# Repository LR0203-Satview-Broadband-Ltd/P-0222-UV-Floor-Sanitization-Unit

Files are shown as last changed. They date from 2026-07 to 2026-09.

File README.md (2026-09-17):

# P-0222 | UV Floor Sanitization Unit

> Low-voltage custom PCB replacing an Arduino-based prototype for a hospital UV floor sanitization platform.

| Project | Status | Current package | Owner |
| --- | --- | --- | --- |
| P-0222 | Released | First Release v1 package complete and ready for supplier release | Ing. Vega Maximiliano |

## Project Overview

Satview Broadband Ltd. is developing a UV foot-sanitizing floor unit for hospital environments. This project replaces the prototype controller with a professional PCB that manages the UV cycle, relay actuation, protected 24 VDC input, power regulation, timer selection, and external component connections.

The current released baseline for the project is the PRD v1.1 package in `project_docs/requirements/PRD v1.1.md`. The design remains under Logic Reliance engineering processes and follows the project requirements, acceptance criteria, and KiCad library governance defined for the work.

## Current Status

The PCB, schematic, and manufacturing reviews were completed. First Release v1 was completed on 2026-08-28 and is ready for supplier release. Review updates include the C5, C7, and C12 part numbers and the D1 and R7 values and part numbers. Review records remain available in `project_docs/requirements/Reviews.md`.

### Package Contents

- BOM: 40 grouped entries and 70 component references.
- Assembly positions: pick-and-place files generated; DNP handling is recorded in the BOM and review notes.
- Component sourcing: manufacturer, MPN, and DigiKey fields populated in the current EBOM.
- Fabrication outputs: Gerbers, ODB++, PTH/NPTH drills, assembly files, drawings, and 3D model present.
- Surface finish: `ENEPIG`.
- Board UID and board specifications added to the `F.Fab` layer and assembly drawing.
- Manufacturing drill outputs: duplicate PTH/NPTH files removed.
- Logic Reliance BOM workbook: editable Excel version generated from the KiCad CSV.

## Technical Scope

- Requirements traceability and acceptance criteria.
- Electrical sizing and power regulation validation.
- STM32C011F6 MCU control.
- Relay-driven UV load switching.
- Reverse-polarity, surge, fuse, and transient protection.
- Configurable cycle timer through DIP switches.
- KiCad schematic capture, PCB layout, manufacturing outputs, and supporting evidence.

## Design Boundaries

This iteration includes the low-voltage PCB only.

Out of scope:

- 120 VAC design, which remains within the external certified power supply.
- Mechanical enclosure design.
- Regulatory certification.
- UV strip sourcing and final optical characterization.

## Manufacturing Package

The manufacturing package is delivered as:

`pcb_0222/outputs/Manufacture/20260828-P_0222_manufacture.zip`

| Directory or file | Purpose |
| --- | --- |
| `Manufacture.Files.rev20280828.zip` | Manufacturing files package |
| `Design.Files.rev20280828.zip` | Design source files |
| `EBOM.rev202608288.xlsx` | Logic Reliance electronic BOM |
| `Mechanical.outputs.rev20280828.zip` | Mechanical outputs |
| `schematics.rev20280828.pdf` | Schematic PDF |
| `Top.View.rev2080828.png` | Board top-view image |

The complete First Release v1 package is available at `pcb_0222/outputs/Releases/v1_20260828/`.

## Repository Contents

This is the controlled inventory of publishable project content. Local process notes, AI working files, and internal assistant configuration are intentionally excluded from publication.

| Directory | Contents |
| --- | --- |
| `pcb_0222/` | KiCad project, schematic, PCB, local library assets, and manufacturing outputs |
| `project_docs/design/` | MCU boot, pinout, power supply, and implementation records |
| `project_docs/datasheets/` | Manufacturer datasheets and component package evidence |
| `project_docs/references/` | External technical references used for engineering decisions |
| `project_docs/requirements/` | Released PRD and processor requirements |

### Design Records

- `mcu_boot/`
- `mcu_pinout/`
- `power_supply/`

### Datasheet Categories

`buttons/` · `conectors/` · `debugger/` · `dipswitch/` · `inductor/` · `leds/` · `mcu/` · `nails/` · `npn/` · `pmos/` · `pptc/` · `psu/` · `relay/` · `rotary/` · `tvs/` · `xtal/` · `zenner/`

Some directory names preserve legacy spelling for traceability, including `conectors/` and `zenner/`.

## Key Documents

- [Project context baseline](p-0222.md)
- [Released PRD](project_docs/requirements/PRD%20v1.1.md)
- [Processor requirements](project_docs/requirements/Processor%20Requirements.md)
- [MCU boot and programming records](project_docs/design/mcu_boot/)
- [MCU pinout records](project_docs/design/mcu_pinout/)
- [Power supply records](project_docs/design/power_supply/)

## General Project Updates

- 2026-07-27: KiCad project files were uploaded and the schematic baseline was published.
- 2026-07-28: SWD programming guidance and STM32C0 BOOT0 handling were documented.
- 2026-07-29: Footprint and datasheet review entered the active validation cycle.
- 2026-07-30: Placement outputs, drawings, STEP model, and exchange artifacts were refreshed.
- 2026-08-02: Schematic review comments were incorporated into the PCB and manufacturing outputs.
- 2026-08-09: Layout placement and routing review continued with synchronized schematic and PCB updates.
- 2026-08-11: The active layout iteration was prepared for formal review.
- 2026-08-16: A preliminary manufacturing package was generated to support the pending layout review.
- 2026-08-16: Board UID and board specifications were added to the `F.Fab` layer and assembly drawing to improve manufacturing traceability.
- 2026-08-18: Repository documentation was refreshed to align the README, project baseline, and automation instructions with the current PRD v1.1 status and the pending formal layout review.
- 2026-08-27: Layout review passed; C5, C7, and C12 part numbers and D1 and R7 values and part numbers were updated.
- 2026-08-28: PCB, schematic, and manufacturing reviews were completed; First Release v1 artifacts were generated under `pcb_0222/outputs/Releases/v1_20260828/`.
- 2026-09-17: The `SP1103C-01UTG` schematic symbol was updated, with the related schematic and PCB project files synchronized.

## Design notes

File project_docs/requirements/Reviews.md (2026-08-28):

# Reviews

# Manufacturing Files Review 2026/08/27 (Blaž)

| | |
| --- | --- |
| 1 | The 3D generated contains the DNP parts as mounted. I don’t think it’s critical for this project, but it worths account for it in future projects.   |
| 2 | The BOM title block got a bit distorded:    Expected (example):   |
| 3 | The description column of the BOM file didn’t fill with the _Description_ field of the symbols but with the _Value_ field.   |
| 4 | I suggest not including schematics in the manufacturing files. This is make reverse engineering more difficult.   |
| 5 | I don’t think it worths adding the bottom silkscreen to the gerber files package as it doesn’t add any relevant information an it implies an additional manufacturing process.   |

# PCB Review 2026/08/26 (Blaž)

| | |
| --- | --- |
| 1 | Make sure there are not rule check errors:  |
| 2 | C3 and C15 are out of stock. But probably not a problem if the board is assembled on China.   |
| 3 | C5 similar case   |
| 4 | C7, C12 similar case   |
| 5 | D1 a bit more critical   |
| 6 | The silkscreen is missing the PCB version (it would be v1 in this case). Example below.   |
| 7 | Did the customer approve the inclusion of our logo in the PCB?   |

# PCB Review 2026/08/16 (Ruslan)

<div class="joplin-table-wrapper"><table style="width: 803px;"><tbody><tr><th colspan="1" rowspan="1" colwidth="49"><p data-id="takswppqcspu">1</p></th><td colspan="1" rowspan="1" colwidth="754"><p data-id="ryoquctkmlhi">Please add the board specs and board stack-up to the “Assembly” layer of the PCB design.</p><p data-id="rygyvwalnciz">Feel free to check an example from this design <a target="_blank" rel="noopener noreferrer nofollow" href="https://github.com/orgs/LR0201-Aura-Axis-Group-Inc/repositories">LR0201-Aura-Axis-Group-Inc repositories</a></p><p data-id="ayjezcmzgbbh">Here is an example:</p></td></tr><tr><th colspan="1" rowspan="1" colwidth="49"><p data-id="udgtshalslsv">2</p></th><td colspan="1" rowspan="1" colwidth="754"><p data-id="yvwvcpwyrcft">Lets add UID to the PCB. The spreadsheet is here: <a target="_blank" rel="noopener noreferrer nofollow" href="https://docs.google.com/spreadsheets/d/1bgarIeeIMzeJS9GwWEmvJlo1JK8DhYBbbADzcFZ2ea8/edit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">PCB UID - Google Sheets</a></p><p data-id="qlhqkcgbeopu">Here an example from a different project:</p><pre><code>PCB NAME
UID vX
[      ] (Blank Square)  </code></pre><p data-id="qwudojhfaxnv">For this project, it could be:</p><pre><code>UV Unit 
HW_00_UV_Unit v1
[      ]   </code></pre></td></tr></tbody></table></div>

# Schematic Review 2026/07/30

<div class="joplin-table-wrapper"><table style="width: 803px;"><tbody><tr><th colspan="1" rowspan="1" colwidth="49"><p data-id="wduerxznfdoq">1</p></th><td colspan="1" rowspan="1" colwidth="754"><p data-id="qwzypgariwlr">According to the PRD, there are X2 strip LED outputs but the schematic only shows 1.</p></td></tr><tr><th colspan="1" rowspan="1" colwidth="49"><p data-id="xseiclundzkz">2</p></th><td colspan="1" rowspan="1" colwidth="754"><p data-id="tzqhzbudwmdk">PRD mentions the addition of a small onboard pushbutton for factory testing. It’s not included in the schematic.</p></td></tr><tr><th colspan="1" rowspan="1" colwidth="49"><p data-id="jewgwryjadsz">3</p></th><td colspan="1" rowspan="1" colwidth="754"><p data-id="hgywgsvytzey">For every component in the circuit, make sure that the following custom parameters are present:</p><ul><li><p data-id="qdgmxtupxijo"><strong>MANUFACTURER:</strong> put here the manufacturer name present in Digikey (can copy it directly from there)</p></li><li><p data-id="ngfopfbhvdoz"><strong>DIGIKEY_PN_CT: </strong>put here the digikey part number defined for cut-tape option.</p></li></ul><div data-type="callout" data-callout-type="warning"><p data-id="jeblmidwpkyu">Add those parameters in the symbols libraries and then update the schematic to bring the changes.</p></div><div data-type="callout" data-callout-type="info"><p data-id="usssqzrqpztj">These two parameters will help to get a full BOM generated by KiCAD compatible with our output template: <a target="_blank" rel="noopener noreferrer nofollow" href="https://docs.google.com/spreadsheets/d/1eHjSh9FfAB-h2eUme77fBcbWqZxTURMp/edit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">https://docs.google.com/spreadsheets/d/1eHjSh9FfAB-h2eUme77fBcbWqZxTURMp/edit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</a></p></div></td></tr><tr><th colspan="1" rowspan="1" colwidth="49"><p data-id="jfwxtkibwmgl">4</p></th><td colspan="1" rowspan="1" colwidth="754"><p data-id="dutiepjwdrad">For defining a component as DNP, use the native KiCAD parameter as shown below.</p><p data-id="pbtvasiaopbf">The symbol will look like the following.</p><div data-type="callout" data-callout-type="info"><p data-id="alquofpocjrm">When using this native parameter, the output BOM generated by KiCAD will contain a column called “DNP“ where every part defined as do not populate will have a “TRUE“ value. This format is compatible with our BOM template.</p></div></td></tr><tr><th colspan="1" rowspan="1" colwidth="49"><p data-id="bytkmqmsajxa">5</p></th><td colspan="1" rowspan="1" colwidth="754"><p data-id="qrnwwgkvwobw">I recommend adding TVS diodes to every exposed contact accessible by human fingers:</p><ul><li><p data-id="acuugdgpkrgm">MCU_SW1</p></li><li><p data-id="rkoeckpmlxfo">MCU_SW2</p></li><li><p data-id="uyebppieljle">SWDIO</p></li><li><p data-id="lynjzwzpnkfu">NRST</p></li><li><p data-id="fzgjaoeihzek">SWCLK</p></li><li><p data-id="cdkruaesdufx">SDA1</p></li><li><p data-id="qfoggkhdkenm">SCL1</p></li><li><p data-id="qexlkqchrlzi">TX1</p></li><li><p data-id="vrxeugsuxpyw">RX1</p></li></ul><div data-type="callout" data-callout-type="info"><p data-id="rfvseltfskjc">There are 3V3 TVS diodes in the library.</p></div></td></tr><tr><th colspan="1" rowspan="1" colwidth="49"><p data-id="gkvzyqcmvkgg">6</p></th><td colspan="1" rowspan="1" colwidth="754"><p data-id="urijaqncadcp">R5 and R9 are swapped. Make R5 = 69.8K and R9 = 22.1K to have 3.3V output.</p></td></tr><tr><th colspan="1" rowspan="1" colwidth="49"><p data-id="lrcsndhfkzic">7</p></th><td colspan="1" rowspan="1" colwidth="754"><p data-id="gfrqojbivzis">Set the “CRITICAL“ parameter as “TRUE“ and make it visible in the schematic for all the parts that are considered as such.</p><div data-type="callout" data-callout-type="info"><p data-id="usdptkkaoxxe">CRITICAL parts are those that require to be populated with the exact part number specified in the shcematic (e.g.: chips, MCUs, connectors, critical transistors, etc…)</p></div></td></tr></tbody></table></div>

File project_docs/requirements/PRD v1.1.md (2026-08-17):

# PRD v1.1

**Project:** P-0222 UV Floor Sanitization Unit  
**Status:** RELEASE  
**Version: 1.1**

**Released:** July 21, 2026

**Last Update:** August 9, 2026

:::info
This Project Requirements Document (PRD) captures the agreed specifications, constraints, and acceptance criteria for the project. It serves as the single reference point that guides every design, development, and testing decision that follows.
:::

---

## 1\. Introduction

### Context

**Satview Broadband Ltd** has spent a few years developing a **UV foot-sanitizing floor unit** for hospitals. A person steps onto the device, and specially engineered UV LED strips (effective range dissipating within ~1 inch of the surface to prevent eye exposure) kill pathogens on the soles of their footwear, reducing room-to-room cross-contamination in high-traffic clinical areas such as nurse stations, operating rooms, and surgical suites.

The current working prototype runs on an Arduino board and relay: 120V AC wall power is stepped down to 24V for eight UV LED strips (75 mA each) and 5V for the Arduino, with a push button triggering a 30-second UV cycle via relay. The objective of **this iteration** is to replace the Arduino-based, hand-wired prototype with a **professional custom PCB**.

The PCB to design will be a low-voltage (24V DC) board carrying the microcontroller, relay, power regulation, configurable-timer DIP switches, and plug-in connectors for all external components, designed for reliability and ready to scale to mass manufacturing. All 120V AC remains in an external certified power supply and never touches the board, keeping the PCB outside medical/safety certification scope. Mechanical/enclosure design, PSU design, regulatory certification, and UV strip sourcing are out of scope for this engagement.

### Q&A

| Question | Answer |
| --- | --- |
| Q1. What is the UV LED strip part number and its electrical rating? | No formal strip datasheet exists; The available technical information is shown on the provided picture   |
| Q2. How does each LED strip terminate, connector or bare pads? | The strip terminates with bare pads, as showmen on the provided pictures   |







---

## 2\. Block Diagrams



---

## 3\. Requirements

<div class="joplin-table-wrapper"><table style="min-width: 228px;"><tbody><tr><th colspan="1" rowspan="1" colwidth="203"><p data-id="kralntoomdes">REQ</p></th><th colspan="1" rowspan="1"><p data-id="tipynbngshax">Description</p></th></tr><tr><td colspan="2" rowspan="1" colwidth="203,0"><h3 data-id="xtzkbxobkbox" id="xtzkbxobkbox">Power Input</h3></td></tr><tr><td colspan="1" rowspan="1" colwidth="203"><p data-id="wrjashymsoul">Specification</p></td><td colspan="1" rowspan="1"><p data-id="cohupxcdpqbe">24 VDC @ 1 A</p></td></tr><tr><td colspan="1" rowspan="1" colwidth="203"><p data-id="saulsnaovtpu">Power Supply</p></td><td colspan="1" rowspan="1"><p data-id="zmmaielhpkxu">External with barrel connector on the enclosure</p><details><summary data-type="detailsSummary">Desktop <a target="_blank" rel="noopener noreferrer nofollow" href="https://www.digikey.com/en/products/detail/ideal-power-ltd/44ATM036T-P240/14303108">44ATM036T-P240 Ideal Power Ltd.</a></summary></details><details><summary data-type="detailsSummary">Barrel connector <a target="_blank" rel="noopener noreferrer nofollow" href="https://www.digikey.com/en/products/detail/mpd-memory-protection-devices/EJ501B/2439533">EJ501B MPD</a></summary></details><details><summary data-type="detailsSummary">Power cord <a target="_blank" rel="noopener noreferrer nofollow" href="https://www.digikey.com/en/products/detail/eaton-tripp-lite/P006-006-15D/10269273">P006-006-15D</a></summary></details></td></tr><tr><td colspan="1" rowspan="1" colwidth="203"><p data-id="nuiqhailyzgd">PCB Input connector</p></td><td colspan="1" rowspan="1"><p data-id="kacfofsoamgx">Connector Header Through Hole, Right Angle 2 position (side entry)</p><p data-id="hnsngkjaacsl">P/N: <a target="_blank" rel="noopener noreferrer nofollow" href="https://www.digikey.com/en/products/detail/phoenix-contact/5442206/4390264">5442206 Phoenix Contact</a></p></td></tr><tr><td colspan="1" rowspan="1" colwidth="203"><p data-id="ajerqjkqpzil">Connector P/N</p></td><td colspan="1" rowspan="1"><p data-id="uipteqchtvbf">P/N: <a target="_blank" rel="noopener noreferrer nofollow" href="https://www.digikey.com/en/products/detail/jst-sales-america-inc/VHR-2N/608624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">VHR-2N JST</a></p><p data-id="cbwllovkqxsg">Cable: 18 AWG (UL 1063)</p></td></tr><tr><td colspan="1" rowspan="1" colwidth="203"><p data-id="nrpdczxhhruq">Protection</p></td><td colspan="1" rowspan="1"><p data-id="boerhlcqtqwj">Include reverse-polarity protection, TVS</p></td></tr><tr><td colspan="1" rowspan="1" colwidth="203"><p data-id="gvokrmmjjitm">Fuse</p></td><td colspan="1" rowspan="1"><p data-id="hxprysfebife">Located on the PCB, immediately after the 24 V input. Use an auto-resetting (PPTC/polyfuse) type to protect the board against short high-current bursts.</p></td></tr><tr><td colspan="2" rowspan="1" colwidth="203,0"><h3 data-id="ldgmzhnwemar" id="ldgmzhnwemar">UV LED Strip Output</h3></td></tr><tr><td colspan="1" rowspan="1" colwidth="203"><p data-id="dxgkionzpvyt">LED Strips</p></td><td colspan="1" rowspan="1"><p data-id="hhkqwjqxrwgo">On/off control of 8 LED strips</p></td></tr><tr><td colspan="1" rowspan="1" colwidth="203"><p data-id="pvksxwdzpfia">Individual strip spec</p></td><td colspan="1" rowspan="1"><p data-id="udzfplpxlinu">24V, 75mA (See spec sheet above)</p></td></tr><tr><td colspan="1" rowspan="1" colwidth="203"><p data-id="wlzspxefhdhr">Connectors</p></td><td colspan="1" rowspan="1"><p data-id="cvqnhqxutnfb">2 connectors (4 strips each)</p></td></tr><tr><td colspan="1" rowspan="1" colwidth="203"><p data-id="pbfoscweisru">Connector orientation</p></td><td colspan="1" rowspan="1"><p data-id="vzsxhxmvpqol">Side entry</p></td></tr><tr><td colspan="1" rowspan="1" colwidth="203"><p data-id="ezyewegpcnzg">Connector P/N</p></td><td colspan="1" rowspan="1"><p data-id="hxritrnvprso">PCB: <a target="_blank" rel="noopener noreferrer" href="https://www.digikey.com/en/products/detail/jst-sales-america-inc/SM08B-PASS-TBT/2773431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">SM08B-PASS-TBT</a></p><p data-id="wlqmxpguemkt">Cable: <a target="_blank" rel="noopener noreferrer nofollow" href="https://www.digikey.com/en/products/detail/jst-sales-america-inc/PAP-08V-S/759980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">PAP-08V-S</a> (JST PA, 8-circuit, 2.0 mm)</p></td></tr><tr><td colspan="2" rowspan="1" colwidth="203,0"><h3 data-id="qxbcrhyrrfpz" id="qxbcrhyrrfpz">LED Strip Wire Harness</h3></td></tr><tr><td colspan="1" rowspan="1" colwidth="203"><p data-id="oxlparbeiuaw">Configuration</p></td><td colspan="1" rowspan="1"><p data-id="wqqzfylgzsun">Each connector carries 4 pairs (Power + GND) to drive 4 LED strips</p></td></tr><tr><td colspan="1" rowspan="1" colwidth="203"><p data-id="byfpbroxgzhq">Cable Length</p></td><td colspan="1" rowspan="1"><p data-id="qinhyittvvov">8 inches</p></td></tr><tr><td colspan="1" rowspan="1" colwidth="203"><p data-id="ortwzzygmsfs">A<span data-comment-id="019f7aa4-5f4f-721d-8346-f022632f6473" class="comment-mark">WG</span></p></td><td colspan="1" rowspan="1"><p data-id="egmwzxhhiqrz"><span data-comment-id="019f7aa4-5f4f-721d-8346-f022632f6473" class="comment-mark">22 AWG</span></p></td></tr><tr><td colspan="2" rowspan="1" colwidth="203,0"><h3 data-id="vlumzwmccobj" id="vlumzwmccobj"><span data-comment-id="019f7aa4-5f4f-721d-8346-f022632f6473" class="comment-mark">Rel</span>ay / LED Switching</h3></td></tr><tr><td colspan="1" rowspan="1" colwidth="203"><p data-id="tkjslmbudmmr">Configuration</p></td><td colspan="1" rowspan="1"><p data-id="casbwxtjttwm">Single mechanical relay driving all 8 LED outputs</p></td></tr><tr><td colspan="1" rowspan="1" colwidth="203"><p data-id="nucqhngqlwfm">Type</p></td><td colspan="1" rowspan="1"><p data-id="dganurffhlce">Normally Open (NO)</p></td></tr><tr><td colspan="1" rowspan="1" colwidth="203"><p data-id="sbpuwnnkqmfd">Relay P/N</p></td><td colspan="1" rowspan="1"><p data-id="vvjtborqgldr"><a target="_blank" rel="noopener noreferrer nofollow" href="https://www.digikey.com/en/products/detail/kemet/EE2-3NUH/5502029">EE2-3NUH KEMET</a></p></td></tr><tr><td colspan="2" rowspan="1" colwidth="203,0"><h3 data-id="pagewgfbpfiw" id="pagewgfbpfiw">User Input</h3></td></tr><tr><td colspan="1" rowspan="1" colwidth="203"><p data-id="lyibtxsbrmiv">Type</p></td><td colspan="1" rowspan="1"><p data-id="ryfqbuqoclft">Two momentary push buttons (or reed switches), each Normally Open (NO), are actuated when a person steps on the unit. The two inputs are logically OR'd, pressing either one triggers a UV cycle. Both provide the same function (redundant/positional coverage); there is no priority between them.</p></td></tr><tr><td colspan="1" rowspan="1" colwidth="203"><p data-id="eglvztzovabl">Connector orientation</p></td><td colspan="1" rowspan="1"><p data-id="rnkypshyqevj">Side entry</p></td></tr><tr><td colspan="1" rowspan="1" colwidth="203"><p data-id="lxdxtopvnvad">Connector P/N</p></td><td colspan="1" rowspan="1"><p data-id="qeypyozfkxum">PCB: <a target="_blank" rel="noopener noreferrer nofollow" href="https://www.digikey.com/en/products/detail/jst-sales-america-inc/SM02B-PASS-TBT/1788574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">SM02B-PASS-TBT</a></p><p data-id="fviruvblltbr">Cable: <a target="_blank" rel="noopener noreferrer nofollow" href="https://www.digikey.com/en/products/detail/jst-sales-america-inc/PAP-02V-S/759974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">PAP-02V-S JST</a></p></td></tr><tr><td colspan="1" rowspan="1" colwidth="203"><p data-id="vlnnthmhheqc">Cable Length</p></td><td colspan="1" rowspan="1"><p data-id="ayxijynrkyal">8 inches</p></td></tr><tr><td colspan="2" rowspan="1" colwidth="203,0"><h3 data-id="gdtawaxlmisf" id="gdtawaxlmisf">Microcontroll<span data-comment-id="019f7aab-8676-7154-b687-727506f62c1d" class="comment-mark">er (MCU)</span></h3></td></tr><tr><td colspan="1" rowspan="1" colwidth="203"><p data-id="vikpvjmnmhmr">P/N</p></td><td colspan="1" rowspan="1"><p data-id="dyhwaaaanaxq"><a target="_blank" rel="noopener noreferrer nofollow" href="https://www.digikey.com/en/products/detail/stmicroelectronics/STM32C011F6P6/17071366">STM32C011F6P6</a></p></td></tr><tr><td colspan="1" rowspan="1" colwidth="203"><p data-id="iswxgdzjxgal">Programming connector</p></td><td colspan="1" rowspan="1"><p data-id="zkyjprvbodww">Use Tag-Connect TC2030-IDC</p></td></tr><tr><td colspan="1" rowspan="1" colwidth="203"><p data-id="vkatzahyyfjd">Programming tool</p></td><td colspan="1" rowspan="1"><p data-id="qdqkqktfxhdg"><a target="_blank" rel="noopener noreferrer nofollow" href="https://www.digikey.com/en/products/detail/stmicroelectronics/ST-LINK-V2/2214535">ST-LINK/V2 STMicroelectronics</a></p><p data-id="wobinipvkzow"><a target="_blank" rel="noopener noreferrer nofollow" href="https://www.tag-connect.com/product/arm20-ctx-20-pin-to-tc2030-idc-adapter-for-cortex">ARM20-CTX 20-Pin to TC2030-IDC</a></p><p data-id="kdmsynaxporr"><a target="_blank" rel="noopener noreferrer nofollow" href="https://www.tag-connect.com/product/tc2030-idc-6-pin-tag-connect-plug-of-nails-spring-pin-cable-with-legs">6-pin small PCB footprint to IDC MCU debug cable</a></p></td></tr><tr><td colspan="2" rowspan="1" colwidth="203,0"><h3 data-id="cqqjibxlxslg" id="cqqjibxlxslg">Timer Configuration (DIP Switch)</h3></td></tr><tr><td colspan="1" rowspan="1" colwidth="203"><p data-id="wtslvzvjnotg">Purpose</p></td><td colspan="1" rowspan="1"><p data-id="dvayguulantd">A mechanical element that allows configuring different timer values</p></td></tr><tr><td colspan="1" rowspan="1" colwidth="203"><p data-id="bnqpwdbgxwov">Type</p></td><td colspan="1" rowspan="1"><p data-id="orurbxdmlizd">Rotary 10-position BCD DIP switch</p></td></tr><tr><td colspan="1" rowspan="1" colwidth="203"><p data-id="yhdifeneznvv">P/N</p></td><td colspan="1" rowspan="1"><p data-id="vrmlfxwsfuyk"><a target="_blank" rel="noopener noreferrer nofollow" href="https://www.digikey.com/en/products/detail/wec/1-1825013-0/13624193">1-1825013-0 TE Connectivity</a></p></td></tr><tr><td colspan="1" rowspan="1" colwidth="203"><p data-id="qeuaamckgnbm">Settings</p></td><td colspan="1" rowspan="1"><ul><li><p data-id="prjuautnntur">0 – 5 s</p></li><li><p data-id="wyfoalhekysh">1 – 10 s</p></li><li><p data-id="mglfoinxcwia">2 – 20 s</p></li><li><p data-id="jefycgakegxu">3 – 30 s</p></li><li><p data-id="yzcppmweawcw">4 – 40 s</p></li><li><p data-id="dpazyywhxieg">5 – 50 s</p></li><li><p data-id="ulzwkfdrcrfj">6 – 60 s</p></li><li><p data-id="mvtqmupppmer">7 – 70 s</p></li><li><p data-id="bxdtpuwspmim">8 – 80 s</p></li><li><p data-id="jsixoovppeur">9 – 90 s</p></li></ul></td></tr><tr><td colspan="2" rowspan="1" colwidth="203,0"><h3 data-id="vlmjcbjomuqr" id="vlmjcbjomuqr">Spare Components (Future-Proofing)</h3></td></tr><tr><td colspan="1" rowspan="1" colwidth="203"><p data-id="uvldkfcmyesx">Spare DIP Switch</p></td><td colspan="1" rowspan="1"><p data-id="onzjehlsuxzl">Add an extra DIP switch to enable additional features/settings in the future if needed</p><p data-id="kribuissbiyb">P/N: <a target="_blank" rel="noopener noreferrer nofollow" href="https://www.digikey.com/en/products/detail/same-sky-formerly-cui-devices/DS04-254-2-02BK-SMT-TR/11310882">DS04-254-2-02BK-SMT-TR Same Sky</a></p></td></tr><tr><td colspan="1" rowspan="1" colwidth="203"><p data-id="swhbptdzgolv">Spare Connector</p></td><td colspan="1" rowspan="1"><p data-id="oloxkciztubl">Include an additional connector exposing 2–4 spare unused MCU pins for future use</p></td></tr><tr><td colspan="2" rowspan="1" colwidth="203,0"><h3 data-id="mroghfrnasfc" id="mroghfrnasfc">Firmware / Control Logic</h3></td></tr><tr><td colspan="1" rowspan="1" colwidth="203"><p data-id="jxzeadjncrtp">Operating Sequence</p></td><td colspan="1" rowspan="1"><p data-id="mqkxvvdpwoia">Relay de-energized (all LED strips off) at power-up. On button press, the MCU energizes the relay, powering all 8 UV LED strips for the configured duration, then de-energizes the relay and returns to idle.</p></td></tr><tr><td colspan="1" rowspan="1" colwidth="203"><p data-id="shwcufleluqp">Timer Selection</p></td><td colspan="1" rowspan="1"><p data-id="vzedgzixfwwk">Cycle duration is read from the rotary DIP switch. The switch is read at the start of each cycle, so the setting can be changed without power-cycling the unit.</p></td></tr><tr><td colspan="1" rowspan="1" colwidth="203"><p data-id="bwljzstctimu">Retrigger Behavior</p></td><td colspan="1" rowspan="1"><p data-id="twiawvgzkgel">If the button is pressed during an active cycle, the press be ignored.</p></td></tr><tr><td colspan="2" rowspan="1" colwidth="203,0"><h3 data-id="nvmhvgzhfond" id="nvmhvgzhfond">Diagnostic / Status Features</h3></td></tr><tr><td colspan="1" rowspan="1" colwidth="203"><p data-id="lwvuolwitmtg">Status LEDs</p></td><td colspan="1" rowspan="1"><p data-id="jmkzwwmsjcom">Include LEDs on the PCB to visually indicate status and operation:</p><ul><li><p data-id="qevaqxymwkvu">24 V input LED</p></li><li><p data-id="sgzyxhrfatcl">MCU VCC LED (+5 V or +3.3 V)</p></li><li><p data-id="kndvpjlczjxm">Active-output LED (relay closed)</p></li><li><p data-id="kywquvuaytxf">MCU status LED (driven by an MCU pin)</p></li></ul></td></tr><tr><td colspan="1" rowspan="1" colwidth="203"><p data-id="ilzpixwklqwe">PCB Pushbutton</p></td><td colspan="1" rowspan="1"><p data-id="hukwjqvumilu">Add a small pushbutton on the PCB, connected to the MCU, to activate the LED output (for factory test)</p></td></tr><tr><td colspan="1" rowspan="1" colwidth="203"><p data-id="rwxtncsqoikg">Test Points</p></td><td colspan="1" rowspan="1"><p data-id="acpcgschmihg">Include test points on all power rails and important signals</p></td></tr><tr><td colspan="2" rowspan="1" colwidth="203,0"><h3 data-id="detffbvvvmay" id="detffbvvvmay">Mechanical / Interface</h3></td></tr><tr><td colspan="1" rowspan="1" colwidth="203"><p data-id="ydtnsaeyaxow">Enclosure</p></td><td colspan="1" rowspan="1"><p data-id="aodbecnlzbby">The enclosure design is custom and is client’s responsibility</p></td></tr><tr><td colspan="1" rowspan="1" colwidth="203"><p data-id="mrrenjsbqgfh">Board Dimensions</p></td><td colspan="1" rowspan="1"><p data-id="kbhwaukjmtir">Available space: 8 x 12 × 1.75 inches (W x L x H)</p></td></tr><tr><td colspan="1" rowspan="1" colwidth="203"><p data-id="onrhbajqnvct">PCB heigh</p></td><td colspan="1" rowspan="1"><p data-id="mvpapilxqmjj">The relay is the tallest component on the board (~9–10 mm) and drives overall PCB height. Component placement should keep this in mind; do not add taller components without confirming enclosure clearance.</p></td></tr><tr><td colspan="1" rowspan="1" colwidth="203"><p data-id="cwudhpoeofcq">Mounting</p></td><td colspan="1" rowspan="1"><p data-id="affvekwrrnnu">4× M3 mounting holes at board corners with keep-out zones</p></td></tr><tr><td colspan="2" rowspan="1" colwidth="203,0"><h3 data-id="zvhlceoimzsq" id="zvhlceoimzsq">Protection &amp; Safety</h3></td></tr><tr><td colspan="1" rowspan="1" colwidth="203"><p data-id="hgyyjgsyfwht">Reverse Polarity</p></td><td colspan="1" rowspan="1"><p data-id="fxbxnccuxgbb">Series P-FET on the 24 V input (see Power Input).</p></td></tr><tr><td colspan="1" rowspan="1" colwidth="203"><p data-id="lhzwbxjaeudy">Overcurrent</p></td><td colspan="1" rowspan="1"><p data-id="inadgqcgdaep">Check Power Inpout → Fuse section</p></td></tr><tr><td colspan="1" rowspan="1" colwidth="203"><p data-id="djgxmuxpvtfu">Transient / Surge</p></td><td colspan="1" rowspan="1"><p data-id="jegxabfmcuay">TVS diode across the 24 V input for surge/ESD protection.</p></td></tr><tr><td colspan="1" rowspan="1" colwidth="203"><p data-id="xxmfwsqbolot">Button Input</p></td><td colspan="1" rowspan="1"><p data-id="ssfcdwsxwlro">TVS/ESD protection</p></td></tr><tr><td colspan="2" rowspan="1" colwidth="203,0"><h3 data-id="riilicxeqagy" id="riilicxeqagy">Operating Environment</h3></td></tr><tr><td colspan="1" rowspan="1" colwidth="203"><p data-id="tmbqkekbicwo">Operating Temperature</p></td><td colspan="1" rowspan="1"><p data-id="nxkbzqraivdn">0 to +40 °C (indoor clinical)</p></td></tr><tr><td colspan="1" rowspan="1" colwidth="203"><p data-id="mhjnzhsqxbqd">Storage Temperature</p></td><td colspan="1" rowspan="1"><p data-id="fymagwwofulq">−20 to +70 °C</p></td></tr><tr><td colspan="1" rowspan="1" colwidth="203"><p data-id="wbyojwfckeyd">Humidity</p></td><td colspan="1" rowspan="1"><p data-id="iqeyrpshyact">10–90 % RH, non-condensing</p></td></tr></tbody></table></div>

## 4\. Acceptance Criteria

### **Required instruments**

- Bench DC power supply (0–30 V, current-limited)
- Digital multimeter
- Programming/debug adapter for the Tag-Connect.
- Stopwatch/timer reference,
- Electronic load or resistive dummy loads sized for the LED strips (Optional)

<div class="joplin-table-wrapper"><table style="min-width: 420px;"><tbody><tr><th colspan="1" rowspan="1" colwidth="395"><p data-id="cngvnmlfycqz">Test Description</p></th><th colspan="1" rowspan="1"><p data-id="jdcefgmocaxb">Expected Results (Acceptance Criteria)</p></th></tr><tr><td colspan="1" rowspan="1" colwidth="395"><h3 data-id="izoegurhnkji" id="izoegurhnkji"><strong>Power Input &amp; Regulation</strong></h3></td><td colspan="1" rowspan="1"></td></tr><tr><td colspan="1" rowspan="1" colwidth="395"><p data-id="wbmyyvbrxopy">Apply 24 VDC @ 1 A (nominal power-up)</p></td><td colspan="1" rowspan="1"><p data-id="dfxshkrlmwzt">Board powers up; MCU rail (+5 V/+3.3 V) within ±5%; inrush does not trip supply; quiescent current within budget</p></td></tr><tr><td colspan="1" rowspan="1" colwidth="395"><p data-id="bsthevtiomfg">Sweep input 22–26 V</p></td><td colspan="1" rowspan="1"><p data-id="otfzeumrfsnf">Board operates normally across the range; MCU rail stays within ±5%</p></td></tr><tr><td colspan="1" rowspan="1" colwidth="395"><p data-id="ocxvindrgsra"><strong>Protection &amp; Safety</strong></p></td><td colspan="1" rowspan="1"></td></tr><tr><td colspan="1" rowspan="1" colwidth="395"><p data-id="ygbytkulrarb">Apply overcurrent above the on-board fuse rating</p></td><td colspan="1" rowspan="1"><p data-id="dmtubgbxoyep">Auto-resetting fuse opens/limits; board recovers after fault removed; no downstream damage</p></td></tr><tr><td colspan="1" rowspan="1" colwidth="395"><p data-id="nvedjoobunry">Apply a reversed 24 V input</p></td><td colspan="1" rowspan="1"><p data-id="tyblaszqxrlc">Series P-FET blocks; no reverse current; board undamaged; works normally when corrected</p></td></tr><tr><td colspan="1" rowspan="1" colwidth="395"><p data-id="cvxabchmifvv"><strong>MCU / Programming</strong></p></td><td colspan="1" rowspan="1"></td></tr><tr><td colspan="1" rowspan="1" colwidth="395"><p data-id="uxlkfosigoxf">Flash firmware via Tag-Connect TC2030-IDC</p></td><td colspan="1" rowspan="1"><p data-id="thrwdnyutnmv">Programming succeeds; MCU runs expected firmware</p></td></tr><tr><td colspan="1" rowspan="1" colwidth="395"><p data-id="lhppjcgmkdeu"><strong>Relay &amp; LED Output</strong></p></td><td colspan="1" rowspan="1"></td></tr><tr><td colspan="1" rowspan="1" colwidth="395"><p data-id="jbwpyqkdveev">Trigger relay (energize)</p></td><td colspan="1" rowspan="1"><p data-id="vihkwayjokxu">All 8 outputs at 24 V; strip current 75 mA ±10% each</p></td></tr><tr><td colspan="1" rowspan="1" colwidth="395"><p data-id="htjeylzoshht">End of cycle (relay release)</p></td><td colspan="1" rowspan="1"><p data-id="cftdffexrkrb">All 8 outputs drop to 0 V; no leakage current</p></td></tr><tr><td colspan="1" rowspan="1" colwidth="395"><p data-id="jfzoladrelqe">Power-up default state</p></td><td colspan="1" rowspan="1"><p data-id="lrzbphvwkobb">Relay de-energized; all strips off before any press</p></td></tr><tr><td colspan="1" rowspan="1" colwidth="395"><p data-id="nteirppkioyr">Verify connector wiring</p></td><td colspan="1" rowspan="1"><p data-id="tzvpxpucijmh">Each 8-circuit connector drives its 4 strips (4 power/GND pairs) with correct polarity</p></td></tr><tr><td colspan="1" rowspan="1" colwidth="395"><p data-id="mgaljhlzyerl"><strong>Timer / DIP Switch</strong></p></td><td colspan="1" rowspan="1"></td></tr><tr><td colspan="1" rowspan="1" colwidth="395"><p data-id="aezkopehdwrn">Run cycle at each rotary position 0–9</p></td><td colspan="1" rowspan="1"><p data-id="fvfnaufzdhbi">Duration matches mapped value (5–90 s) within ±5%, whichever is greater</p></td></tr><tr><td colspan="1" rowspan="1" colwidth="395"><p data-id="pfbyppgrrvvr">Change the setting mid-idle, then trigger</p></td><td colspan="1" rowspan="1"><p data-id="peohvttiguwx">New duration applies to the next cycle without power-cycling</p></td></tr><tr><td colspan="1" rowspan="1" colwidth="395"><p data-id="szblyeiymchb"><strong>User Input</strong></p></td><td colspan="1" rowspan="1"></td></tr><tr><td colspan="1" rowspan="1" colwidth="395"><p data-id="kypxjxpnatjo">Press button 1 from idle</p></td><td colspan="1" rowspan="1"><p data-id="vgepxyznazco">Cycle starts, runs configured duration, returns to idle</p></td></tr><tr><td colspan="1" rowspan="1" colwidth="395"><p data-id="rithycakeivc">Press button 2 from idle</p></td><td colspan="1" rowspan="1"><p data-id="nwmusjychwdy">Same result (logical OR of the two inputs confirmed)</p></td></tr><tr><td colspan="1" rowspan="1" colwidth="395"><p data-id="adiadeugkrol">Press either button during the active cycle</p></td><td colspan="1" rowspan="1"><p data-id="ndnchzhegtkt">Press ignored; cycle continues original duration</p></td></tr><tr><td colspan="1" rowspan="1" colwidth="395"><p data-id="txinzljuyplt"><strong>Diagnostics</strong></p></td><td colspan="1" rowspan="1"></td></tr><tr><td colspan="1" rowspan="1" colwidth="395"><p data-id="mokmuzviwibe">Check status LEDs under each condition</p></td><td colspan="1" rowspan="1"><p data-id="dbdvykyjdwmc">24 V input LED (power applied), MCU VCC LED (rail up), active-output LED (relay closed), MCU status LED (heartbeat) all behave correctly</p></td></tr></tbody></table></div>

# 5\. Changelog

## v1.1 - August 9, 2026

Updated the PCB power input connector (replace screw terminal with JST)

## v1.0 - July 21, 2026

Original document release

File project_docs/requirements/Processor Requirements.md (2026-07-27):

# Processor Requirements

## Power Requirements

| Parameter | Value |
| --- | --- |
| Battery powered | NO  |
| Battery info | |
| Battery life | |
| Sleep / Wake-up | |
| Operation Voltage | N/A |
| Other | |

## Peripherals Requirements

Use this table to indicate peripheral requirements.

- **Qty required:** How many peripherals of this kind are required (e.g., 1 SPI, 2 UARTs)
- **Pins used:** How many pins will be required for the peripheral (e.g., 2 UARTs need 4 pins: 2×TX, 2×RX)
- **Notes:** Additional information specific to the given peripheral
- **Total number of pins:** How many pins for all peripherals including GPIOs are needed

| Peripheral | Qty Required | Pins Used | Notes (Any specific requirements?) |
| --- | --- | --- | --- |
| GPIO | 2 | 2 | Switch input |
| | 1 | 1 | Debug button |
| | 1 | 1 | Debug LED |
| | 1 | 1 | Relay output |
| | 1 | 4 | DIP Switch 1 |
| | 1 | 2 | DIP Switch 2 |
| | 1 | 2 | Spare |
| | | | |
| | | | |
| | | | |
| | | | |
| | | | |
| | | | |
| **Total Number of IOs** | | 13  | |

## Wireless Requirements

Use this section in case we are selecting a SoC or Module with wireless capabilities.

| Protocol | Required? | Notes (Any specific requirements?) |
| --- | --- | --- |
| Bluetooth | No  | Bluetooth Classic Profile (SPP 1.1, A2DP, etc) Bluetooth Low Energy (4.0, 4.2, 5, etc) |
| WiFi | No  | Speed requirements Firmware requirements (specific protocol / library) |
| Zigbee | No  | |
| Other? | No  | |

## Memory and Processing Power

| Parameter | Value |
| --- | --- |
| Flash memory | |
| EEPROM memory | |
| RAM memory | |
| Processor speed | |
| Programming / Debug | Using TC2030 and inexpensive programmer |
| In-field firmware update | |
| Other | |

## Other Requirements

| Parameter | Value |
| --- | --- |
| Package size / type | |
| Automotive | No  |
| Temperature rating | 0 to +40 °C |
| Budgetary / BOM | |
| Stock / Production Qty | Minimum stock availability for production? |
| Other | |

## Selected Options

Please spec here the options you selected (in case there are several).

### Option 1

| Parameter | Value |
| --- | --- |
| Manufacturer and Part No | STM32C011F6 |
| Manufacturer link | [STM32C011F6 \| Product - STMicroelectronics](https://www.st.com/en/microcontrollers-microprocessors/stm32c011f6.html#overview) |
| Digikey / Mouser / etc link | [STM32C011F6P6 STMicroelectronics \| Microcontrollers \| DigiKey](https://www.digikey.com/en/products/detail/stmicroelectronics/STM32C011F6P6/17071366) |
| Dev board information | [STM32C0116-DK \| Product - STMicroelectronics](https://www.st.com/en/evaluation-tools/stm32c0116-dk.html#sample-buy)  [STM32C0116-DK STMicroelectronics \| Embedded MCU, DSP Evaluation Boards \| DigiKey](https://www.digikey.com/en/products/detail/stmicroelectronics/STM32C0116-DK/17074591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) |
| Programmer | [ST-LINK/V2 STMicroelectronics](https://www.digikey.com/en/products/detail/stmicroelectronics/ST-LINK-V2/2214535)  [ARM20-CTX 20-Pin to TC2030-IDC](https://www.tag-connect.com/product/arm20-ctx-20-pin-to-tc2030-idc-adapter-for-cortex)  [6-pin small PCB footprint to IDC MCU debug cable](https://www.tag-connect.com/product/tc2030-idc-6-pin-tag-connect-plug-of-nails-spring-pin-cable-with-legs) |
| Pros for this option | |
| Cons for this option | |

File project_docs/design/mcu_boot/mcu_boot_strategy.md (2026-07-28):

# STM32C011F6P6 Boot and Programming Implementation Report

## Scope
This report summarizes the boot architecture and firmware programming interfaces currently implemented for the STM32C011F6P6 in project P-0222, and identifies provisional alternatives retained for recovery scenarios.

## Implemented Boot Configuration
- The selected option-byte configuration is nBOOT_SEL = 0.
- Under this configuration, BOOT0 is sampled during reset.
- The intended default behavior is direct startup from user Flash in normal operation.

## Implemented Hardware Behavior (No External Tool Connected)
- No external pull-down resistor was implemented on PA14/BOOT0.
- This implementation is aligned with STM32C0 reset behavior documented by ST: after reset, PA14 is configured for SWD alternate function and an internal pull-down on PA14 is enabled, while an internal pull-up on PA13 is enabled.
- Based on this behavior, the default reset condition keeps BOOT0 at a defined low level and the device boots from user Flash.
- The NRST network includes a local 100 nF capacitor from PF2/NRST to GND, placed close to the MCU.
- Manual reset pushbutton provision on NRST remains optional.

## Implemented Primary Programming Interface (SWD)
SWD was defined as the primary programming and debug interface using ST-LINK/V2, ARM20-CTX, and TC2030-IDC.

TC2030 6-pin assignment:

| TC2030 pad | SWD signal | STM32C011F6P6 pin |
| --- | --- | --- |
| 1 | VREF | VDD |
| 2 | SWDIO | PA13 |
| 3 | NRST | PF2/NRST |
| 4 | SWCLK | PA14/BOOT0 |
| 5 | GND | VSS |
| 6 | SWO/TDO | Not connected |

Associated electrical criteria:
- VREF is used by ST-LINK for target I/O level detection; the target board is externally powered during programming.
- SWDIO, SWCLK, NRST, and GND are routed as short and low-noise connections to improve debug robustness.

## Provisional Recovery Alternatives (System Memory Bootloader)
The following interfaces remain available as provisional recovery/update options when SWD access is not available.

### Bootloader Entry Condition
- BOOT0 forced high during reset.
- NRST toggled with nBOOT_SEL = 0 active.
- Resulting mode: System Memory bootloader.

### Provisional Alternative A: USART
- Reserved access points: PA11, PA12, GND.
- Intended usage: temporary firmware recovery/programming path.

### Provisional Alternative B: I2C
- Reserved access points: PB6 (I2C1_SCL), PB7 (I2C1_SDA), GND.
- Electrical condition: external pull-ups on SCL and SDA, nominal 4.7 kOhm to VDD.

## Consolidated Status
- Implemented as baseline: SWD programming/debug and Flash boot in normal operation.
- Retained as provisional: USART and I2C bootloader-based recovery paths.

## Pending Technical Validation
Before design release, final verification remains required against the latest STM32C011F6P6 documentation set (datasheet and AN2606), specifically for System Memory interface mapping and boot-mode behavior by package and silicon revision.

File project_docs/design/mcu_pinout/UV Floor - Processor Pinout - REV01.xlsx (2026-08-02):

Pin Nr | Pin Name | Feature | MCU Peripheral / Channel | Schematic Label | Details
1 | PB7 | Reserved (Debug) | PB7 | SCL1 | With BOOT0 = 1 : programming I2C bus With BOOT0 = 0 (Default): I2C or GPIO peripheral | Reserved, do not use
2 | PC14-OSCX-IN | XTAL-IN | PC14 | MCU_DIP1 | GPIO : DIP Switch for future expantion | Can be used repurposed
3 | PC15-OSCX_OUT | XTAL-IN | PC15 | MCU_DIP2 | GPIO : DIP Switch for future expantion | Free to use
4 | VDD/VDDA | Power | VDD | +3V3
5 | VSS/VSSA | Power | GND | GND
6 | PF2-NRST | System Reset | PF2 | NRST | HW Reset + SWD Reset Pin
7 | PA0 | Led Strips Control | PA0 | MCU_RELAY | High: Strips ON - Low: Strips OFF
8 | PA1 | Debug | PA1 | MCU_LED | High: Led OFF - Low: Led ON
9 | PA2 | Presence Switch | PA2 | MCU_SW1 | High: Switch OPEN - Low: Swicth CLOSE
10 | PA3 | Presence Switch | PA3 | MCU_SW2 | High: Switch OPEN - Low: Swicth CLOSE
11 | PA4 | Time Selection | PA4 | MCU_BCD0 | High: Default STATE (Pull Up)
12 | PA5 | Time Selection | PA5 | MCU_BCD1 | High: Default STATE (Pull Up)
13 | PA6 | Time Selection | PA6 | MCU_BCD2 | High: Default STATE (Pull Up)
14 | PA7 | Time Selection | PA7 | MCU_BCD3 | High: Default STATE (Pull Up)
15 | PA8 | Debug | PA8 | MCU_TEST | Press: Low - Non Press: High
16 | PA11 [PA9] | Reserved (Debug) | PA11 | TX1 | With BOOT0 = 1 : programming USART bus With BOOT0 = 0 (Default): USART or GPIO peripheral
17 | PA12 [PA10] | Reserved (Debug) | PA12 | RX1 | With BOOT0 = 1 : programming USART bus With BOOT0 = 0 (Default): USART or GPIO peripheral
18 | PA13 | Reserved (Strap) | PA13 | SWDIO | SWD Port
19 | PA14-BOOT0 | Reserved (Strap) | PA14 | SWCLK | SWD Port (Default) or BOOT selection
20 | PB6 | Reserved (Debug) | PB6 | SDA1 | With BOOT0 = 1 : programming I2C bus With BOOT0 = 0 (Default): I2C or GPIO peripheral

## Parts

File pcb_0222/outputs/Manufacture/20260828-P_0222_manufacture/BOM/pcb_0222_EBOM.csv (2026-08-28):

Reference | Qty | DNP | CRITICAL | DIGIKEY_PN_CT | MANUFACTURER | PARTNO | Description | #
C1,C4,C6,C11,C13,C14 | 6 |  |  | 399-C0603C104K5RACTUCT-ND | KEMET | C0603C104K5RACTU | CAP CER 0.1UF 50V X7R 0603 | 1
C2 | 1 |  |  | 478-KGM15ACG1H1R0CT-ND | KYOCERA AVX | 06035A1R0CAT2A | CAP CER 1PF 50V C0G/NP0 0603 | 2
C3,C15 | 2 |  |  | 1276-6794-1-ND | Samsung Electro-Mechanics | CL10A475KL8NRNC | CAP CER 4.7UF 35V X5R 0603 | 3
C5 | 1 |  |  | 4713-GMC10X7R106K10NTCT-ND | Cal-Chip Electronics, Inc. | GMC10X7R106K10NT | CAP0603 X7R 10UF 10% 10V | 4
C7,C12 | 2 |  |  | 445-CGA6P1X7S1N106K250AECT-ND | TDK | CGA6P1X7S1N106K250AE | 10 µF ±10% 75V Ceramic Capacitor X7S 1210 (3225 Metric) | 5
C8,C9,C10 | 3 |  |  | 478-KGM15AR71H103KTCT-ND | KYOCERA AVX | KGM15AR71H103KT | CAP CER 10000PF 50V X7R 0603 | 6
D1 | 1 |  |  | 4878-BZT52C5V1CT-ND | Diotec Semiconductor | BZT52C5V1 | DIODE ZENER 5.1V 500MW SOD123F | 7
D2 | 1 |  |  | 5399-B5819WCT-ND | Shenzhen Slkormicro Semicon Co., Ltd. | B5819W | DIODE SCHOTTKY 40V 1A SOD123 | 8
F1 | 1 |  |  | 5923-0ZCF0100AF2ACT-ND | Bel Fuse Inc. | 0ZCF0100AF2A | PTC RESET FUSE 60V 1A | 9
J1 | 1 |  |  | 455-S2P-VH-ND | JST Sales America Inc. | S2P-VH | CONN HEADER R/A 2POS 3.96MM | 10
J2,J3 | 2 |  |  | 455-SM02B-PASS-TBTCT-ND | JST Sales America Inc. | SM02B-PASS-TBT | CONN HEADER SMD R/A 2POS 2MM | 11
J4,J6 | 2 |  |  | 455-SM08B-PASS-TBTCT-ND | JST Sales America Inc. | SM08B-PASS-TBT | CONN HEADER SMD R/A 8POS 2MM | 12
J7,J9 | 2 | DNP |  | 732-5317-ND | Würth Elektronik | 61300411121 | Connector Header Through Hole 4 position 0.100" (2.54mm) | 13
J8 | 1 | DNP |  | 609-4434-ND | Amphenol ICC (FCI) | 77311-118-02LF | Connector Header Through Hole 2 position 0.100" (2.54mm) | 14
K1 | 1 |  | TRUE | 399-EE2-3NUH-ND | KEMET | EE2-3NUH | RELAY GENERAL PURPOSE DPDT 2A 3V | 15
L1 | 1 |  |  | SRR6038-120YCT-ND | Bourns Inc. | SRR6038-120Y | FIXED IND 12UH 1.7A 53 MOHM SMD | 16
LED1,LED2 | 2 |  |  | 160-LTST-C190GKTCT-ND | Lite-On Inc. | LTST-C190GKT | Green 569nm LED Indication - Discrete 2.1V 0603 (1608 Metric) | 17
LED3 | 1 |  | NO | 160-1437-1-ND | Lite-On Inc. | LTST-C190KSKT | Yellow 591nm LED Indication - Discrete 2.1V 0603 (1608 Metric) | 18
LED4 | 1 |  | NO | 160-1436-1-ND | Lite-On Inc. | LTST-C190KRKT | Red 631nm LED Indication - Discrete 2V 0603 (1608 Metric) | 19
PB1 | 1 |  |  | 7914J-1-000-ND | Bourns Inc. | 7914J-1-000 | SWITCH TACTILE SPST-NO 0.1A 16V | 20
Q1 | 1 |  | TRUE | BSP170PH6327XTSA1CT-ND | Infineon Technologies | BSP170PH6327XTSA1 | MOSFET P-CH 60V 1.9A SOT223-4 | 21
Q2 | 1 |  |  | 5399-BC817-16CT-ND | Shenzhen Slkormicro Semicon Co., Ltd. | BC817-16 | Bipolar (BJT) Transistor NPN 45 V 500 mA 100MHz 200 mW Surface Mount SOT-323 | 22
R1,R2 | 2 |  |  | RMCF0603ZT0R00CT-ND | Stackpole Electronics Inc | RMCF0603ZT0R00 | RES 0 OHM JUMPER 1/10W 0603 | 23
R3 | 1 |  |  | 1712-CRGH1206F2K2CT-ND | TE Connectivity Passive Product | CRGH1206F2K2 | RES 2.2K OHM 1% 1/2W 1206 | 24
R4 | 1 |  |  | 541-2.87MHCT-ND | Vishay Dale | CRCW06032M87FKEA | RES SMD 2.87M OHM 1% 1/8W 0603 | 25
R5 | 1 |  |  | 311-69.8KHRCT-ND | YAGEO | RC0603FR-0769K8L | RES 69.8K OHM 1% 1/10W 0603 | 26
R6,R19,R20 | 3 |  |  | 13-RC0603FR-13120RLCT-ND | YAGEO | RC0603FR-13120RL | RES 120 OHM 1% 1/10W 0603 | 27
R7 | 1 |  |  | 311-3.60KFRCT-ND | YAGEO | RC1206FR-073K6L | RES 3.6K OHM 1% 1/4W 1206 | 28
R8 | 1 |  |  | 541-200KHCT-ND | Vishay Dale | CRCW0603200KFKEA | RES SMD 200K OHM 1% 1/8W 0603 | 29
R9 | 1 |  |  | 311-22.1KHRCT-ND | YAGEO | RC0603FR-0722K1L | RES 22.1K OHM 1% 1/10W 0603 | 30
R10,R11,R12,R13,R14,R15,R16,R17,R18 | 9 |  |  | 311-10.0KHRCT-ND | YAGEO | RC0603FR-0710KL | RES 10K OHM 1% 1/10W 0603 | 31
R21 | 1 |  |  | RMCF0603FT1K00CT-ND | Stackpole Electronics Inc | RMCF0603FT1K00 | RES 1K OHM 1% 1/10W 0603 | 32
R22,R23 | 2 | DNP |  | P4.70KHCT-ND | Panasonic Industry | ERJ-3EKF4701V | RES SMD 4.7K OHM 1% 1/10W 0603 | 33
S1 | 1 |  |  | 2223-DS04-254-2-02BK-SMT-CT-ND | Same Sky (Formerly CUI Devices) | DS04-254-2-02BK-SMT-TR | SWITCH SLIDE DIP SPST 0.025A 24V | 34
S2 | 1 |  |  | CKN6158-ND | C&K | CD10RM0SB | Dip Switch BCD 10 Position Surface Mount Rotary for Tool Actuator 0.4VA 20VAC/DC | 35
TVS1 | 1 |  |  | 18-SMAJ26CACT-ND | Littelfuse Inc. | SMAJ26CA | Vstand 26V - 42.1V Clamp 9.5A Ipp 400W Tvs Diode Surface Mount DO-214AC (SMA) | 36
TVS2,TVS3,TVS4,TVS6 | 4 |  |  | F10154CT-ND | Littelfuse Inc. | SP1103C-01UTG | TVS DIODE 3.3VWM 9VC 2DFN | 37
TVS5,TVS7,TVS8 | 3 | DNP |  | 497-5235-1-ND | STMicroelectronics | USBLC6-2SC6 | TVS DIODE 5.25VWM 17VC SOT23-6 | 38
U1 | 1 |  | TRUE | 296-LMR54406DBVRCT-ND | Texas Instruments | LMR54406DBVR | Buck Switching Regulator IC Positive Adjustable 0.8V 1 Output 600mA SOT-23-6 | 39
U2 | 1 |  | TRUE | 497-STM32C011F6P6-ND | STMicroelectronics | STM32C011F6P6 | IC MCU 32BIT 32KB FLASH 20TSSOP | 40

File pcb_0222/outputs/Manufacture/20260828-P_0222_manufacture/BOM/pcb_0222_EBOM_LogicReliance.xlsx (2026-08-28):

 |  |  |  |  |  | PCBA Bill of Materials
 |  |  |  |  |  | Company: | Logic Reliance
 |  |  |  |  |  | Project ID: | LR0203-0000 (P-0222)
 |  |  |  |  |  | Project Title: | UV Floor Sanitization Unit
 |  |  |  |  |  | Version: | v1.0
Notes:
* Parts specified with the CRITICAL field as TRUE must be the exact manufacturer and part number. For other parts, alternative components that meet the same specifications can be considered.
* Parts specified as DNP (Do Not Populate) must not be populated.
# | DESIGNATOR | DNP | CRITICAL | QTY | MANUFACTURER | MPN | DIGIKEY_PN_CT | DESCRIPTION
1 | C1,C4,C6,C11,C13,C14 | NO | FALSE | 6 | KEMET | C0603C104K5RACTU | 399-C0603C104K5RACTUCT-ND | CAP CER 0.1UF 50V X7R 0603
2 | C2 | NO | FALSE | 1 | KYOCERA AVX | 06035A1R0CAT2A | 478-KGM15ACG1H1R0CT-ND | CAP CER 1PF 50V C0G/NP0 0603
3 | C3,C15 | NO | FALSE | 2 | Samsung Electro-Mechanics | CL10A475KL8NRNC | 1276-6794-1-ND | CAP CER 4.7UF 35V X5R 0603
4 | C5 | NO | FALSE | 1 | Cal-Chip Electronics, Inc. | GMC10X7R106K10NT | 4713-GMC10X7R106K10NTCT-ND | CAP0603 X7R 10UF 10% 10V
5 | C7,C12 | NO | FALSE | 2 | TDK | CGA6P1X7S1N106K250AE | 445-CGA6P1X7S1N106K250AECT-ND | 10 µF ±10% 75V Ceramic Capacitor X7S 1210 (3225 Metric)
6 | C8,C9,C10 | NO | FALSE | 3 | KYOCERA AVX | KGM15AR71H103KT | 478-KGM15AR71H103KTCT-ND | CAP CER 10000PF 50V X7R 0603
7 | D1 | NO | FALSE | 1 | Diotec Semiconductor | BZT52C5V1 | 4878-BZT52C5V1CT-ND | DIODE ZENER 5.1V 500MW SOD123F
8 | D2 | NO | FALSE | 1 | Shenzhen Slkormicro Semicon Co., Ltd. | B5819W | 5399-B5819WCT-ND | DIODE SCHOTTKY 40V 1A SOD123
9 | F1 | NO | FALSE | 1 | Bel Fuse Inc. | 0ZCF0100AF2A | 5923-0ZCF0100AF2ACT-ND | PTC RESET FUSE 60V 1A
10 | J1 | NO | FALSE | 1 | JST Sales America Inc. | S2P-VH | 455-S2P-VH-ND | CONN HEADER R/A 2POS 3.96MM
11 | J2,J3 | NO | FALSE | 2 | JST Sales America Inc. | SM02B-PASS-TBT | 455-SM02B-PASS-TBTCT-ND | CONN HEADER SMD R/A 2POS 2MM
12 | J4,J6 | NO | FALSE | 2 | JST Sales America Inc. | SM08B-PASS-TBT | 455-SM08B-PASS-TBTCT-ND | CONN HEADER SMD R/A 8POS 2MM
13 | J7,J9 | YES | FALSE | 2 | Würth Elektronik | 61300411121 | 732-5317-ND | Connector Header Through Hole 4 position 0.100" (2.54mm)
14 | J8 | YES | FALSE | 1 | Amphenol ICC (FCI) | 77311-118-02LF | 609-4434-ND | Connector Header Through Hole 2 position 0.100" (2.54mm)
15 | K1 | NO | TRUE | 1 | KEMET | EE2-3NUH | 399-EE2-3NUH-ND | RELAY GENERAL PURPOSE DPDT 2A 3V
16 | L1 | NO | FALSE | 1 | Bourns Inc. | SRR6038-120Y | SRR6038-120YCT-ND | FIXED IND 12UH 1.7A 53 MOHM SMD
17 | LED1,LED2 | NO | FALSE | 2 | Lite-On Inc. | LTST-C190GKT | 160-LTST-C190GKTCT-ND | Green 569nm LED Indication - Discrete 2.1V 0603 (1608 Metric)
18 | LED3 | NO | FALSE | 1 | Lite-On Inc. | LTST-C190KSKT | 160-1437-1-ND | Yellow 591nm LED Indication - Discrete 2.1V 0603 (1608 Metric)
19 | LED4 | NO | FALSE | 1 | Lite-On Inc. | LTST-C190KRKT | 160-1436-1-ND | Red 631nm LED Indication - Discrete 2V 0603 (1608 Metric)
20 | PB1 | NO | FALSE | 1 | Bourns Inc. | 7914J-1-000 | 7914J-1-000-ND | SWITCH TACTILE SPST-NO 0.1A 16V
21 | Q1 | NO | TRUE | 1 | Infineon Technologies | BSP170PH6327XTSA1 | BSP170PH6327XTSA1CT-ND | MOSFET P-CH 60V 1.9A SOT223-4
22 | Q2 | NO | FALSE | 1 | Shenzhen Slkormicro Semicon Co., Ltd. | BC817-16 | 5399-BC817-16CT-ND | Bipolar (BJT) Transistor NPN 45 V 500 mA 100MHz 200 mW Surface Mount SOT-323
23 | R1,R2 | NO | FALSE | 2 | Stackpole Electronics Inc | RMCF0603ZT0R00 | RMCF0603ZT0R00CT-ND | RES 0 OHM JUMPER 1/10W 0603
24 | R3 | NO | FALSE | 1 | TE Connectivity Passive Product | CRGH1206F2K2 | 1712-CRGH1206F2K2CT-ND | RES 2.2K OHM 1% 1/2W 1206
25 | R4 | NO | FALSE | 1 | Vishay Dale | CRCW06032M87FKEA | 541-2.87MHCT-ND | RES SMD 2.87M OHM 1% 1/8W 0603
26 | R5 | NO | FALSE | 1 | YAGEO | RC0603FR-0769K8L | 311-69.8KHRCT-ND | RES 69.8K OHM 1% 1/10W 0603
27 | R6,R19,R20 | NO | FALSE | 3 | YAGEO | RC0603FR-13120RL | 13-RC0603FR-13120RLCT-ND | RES 120 OHM 1% 1/10W 0603
28 | R7 | NO | FALSE | 1 | YAGEO | RC1206FR-073K6L | 311-3.60KFRCT-ND | RES 3.6K OHM 1% 1/4W 1206
29 | R8 | NO | FALSE | 1 | Vishay Dale | CRCW0603200KFKEA | 541-200KHCT-ND | RES SMD 200K OHM 1% 1/8W 0603
30 | R9 | NO | FALSE | 1 | YAGEO | RC0603FR-0722K1L | 311-22.1KHRCT-ND | RES 22.1K OHM 1% 1/10W 0603
31 | R10,R11,R12,R13,R14,R15,R16,R17,R18 | NO | FALSE | 9 | YAGEO | RC0603FR-0710KL | 311-10.0KHRCT-ND | RES 10K OHM 1% 1/10W 0603
32 | R21 | NO | FALSE | 1 | Stackpole Electronics Inc | RMCF0603FT1K00 | RMCF0603FT1K00CT-ND | RES 1K OHM 1% 1/10W 0603
33 | R22,R23 | YES | FALSE | 2 | Panasonic Industry | ERJ-3EKF4701V | P4.70KHCT-ND | RES SMD 4.7K OHM 1% 1/10W 0603
34 | S1 | NO | FALSE | 1 | Same Sky (Formerly CUI Devices) | DS04-254-2-02BK-SMT-TR | 2223-DS04-254-2-02BK-SMT-CT-ND | SWITCH SLIDE DIP SPST 0.025A 24V
35 | S2 | NO | FALSE | 1 | C&K | CD10RM0SB | CKN6158-ND | Dip Switch BCD 10 Position Surface Mount Rotary for Tool Actuator 0.4VA 20VAC/DC
36 | TVS1 | NO | FALSE | 1 | Littelfuse Inc. | SMAJ26CA | 18-SMAJ26CACT-ND | Vstand 26V - 42.1V Clamp 9.5A Ipp 400W Tvs Diode Surface Mount DO-214AC (SMA)
37 | TVS2,TVS3,TVS4,TVS6 | NO | FALSE | 4 | Littelfuse Inc. | SP1103C-01UTG | F10154CT-ND | TVS DIODE 3.3VWM 9VC 2DFN
38 | TVS5,TVS7,TVS8 | YES | FALSE | 3 | STMicroelectronics | USBLC6-2SC6 | 497-5235-1-ND | TVS DIODE 5.25VWM 17VC SOT23-6
39 | U1 | NO | TRUE | 1 | Texas Instruments | LMR54406DBVR | 296-LMR54406DBVRCT-ND | Buck Switching Regulator IC Positive Adjustable 0.8V 1 Output 600mA SOT-23-6
40 | U2 | NO | TRUE | 1 | STMicroelectronics | STM32C011F6P6 | 497-STM32C011F6P6-ND | IC MCU 32BIT 32KB FLASH 20TSSOP

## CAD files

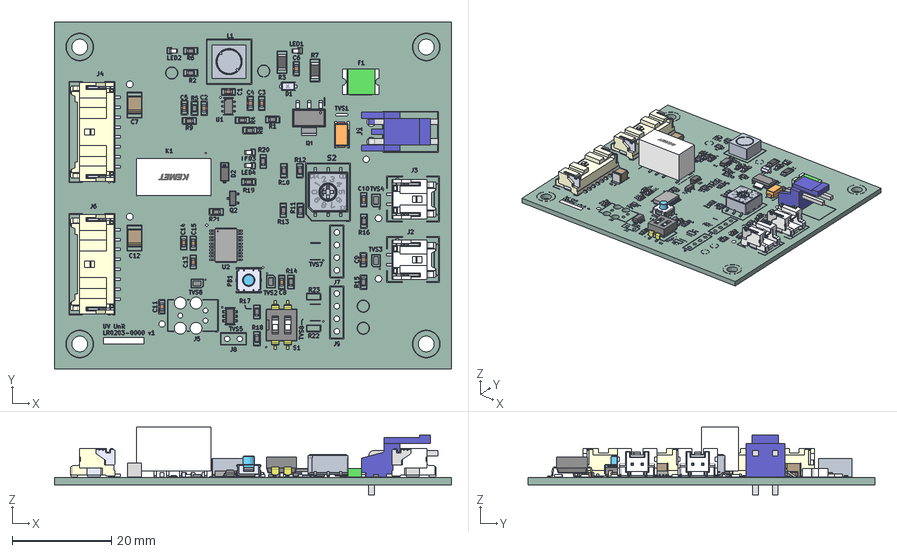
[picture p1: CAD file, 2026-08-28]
pcb_0222/outputs/Manufacture/20260828-P_0222_manufacture/3D/P_0222_MODEL.step
80.0 x 70.0 x 13.7 mm
AC0603FR-1047KL x 19
KEMET_X7R_C0603CCJ x 13
SOD123F Lead
SOD123F lower body
SOD123F upper body
SRR6038
SP1103C-01UTG x 4
025002-01643-a.testprt
��1
��2
Pin1Body.STEP x 2
Pin2Body.STEP x 2
CeramicBody.STEP x 2
CoatingBody.STEP x 2
SM08B-PASS-TBT x 2
0ZCF0100AF2A
PinsArrayL
FilletPinR
LTST-C194TBKT x 4
SMD-MOSFET-P-CH-60V-900MA_SOT-23_.step
CD10XM0S_SW0001_PRT
IR_TEE2MFS_L15W7.5H10
7914J-1-000E
SM02B-PASS-TBT(LF)(SN) x 2
SI3865DDV-T1-GE3
CUI_DEVICES_DS04-254-2-02BK-SMT-TR
S2P-VH
pcb_0222_silkscreen x 2
pcb_0222_PCB

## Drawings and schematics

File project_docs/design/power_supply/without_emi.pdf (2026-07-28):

## WEBENCH ® Design Report

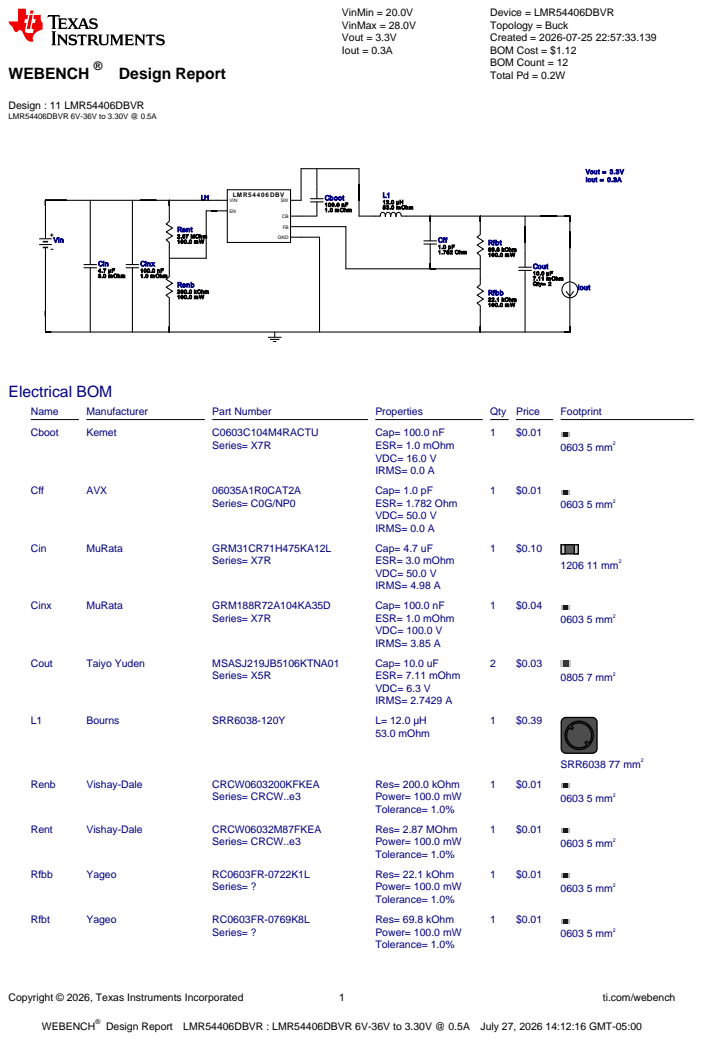
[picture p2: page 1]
Copyright © 2026, Texas Instruments Incorporated; ti.com/webench; WEBENCH®; Design : 11 LMR54406DBVR LMR54406DBVR 6V-36V to 3.30V @ 0.5A; VinMin = 20.0V VinMax = 28.0V Vout = 3.3V Iout = 0.3A; Device = LMR54406DBVR Topology = Buck Created = 2026-07-25 22:57:33.139 BOM Cost = $1.12 BOM Count = 12 Total Pd = 0.2W; Cinx 100.0 nF 1.0 m Ohm; Cff 1.0 pF 1.782 Ohm; L1 12.0 µH 53.0 m Ohm; LM R5 4 4 0 6 DBV; GND; VIN; Rfbb 22.1 kOhm 100.0 m W; Rfbt 69.8 kOhm 100.0 m W; Vout = 3.3V Iout = 0.3A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

Design Report LMR54406DBVR : LMR54406DBVR 6V-36V to 3.30V @ 0.5A July 27, 2026 14:12:16 GMT-05:00

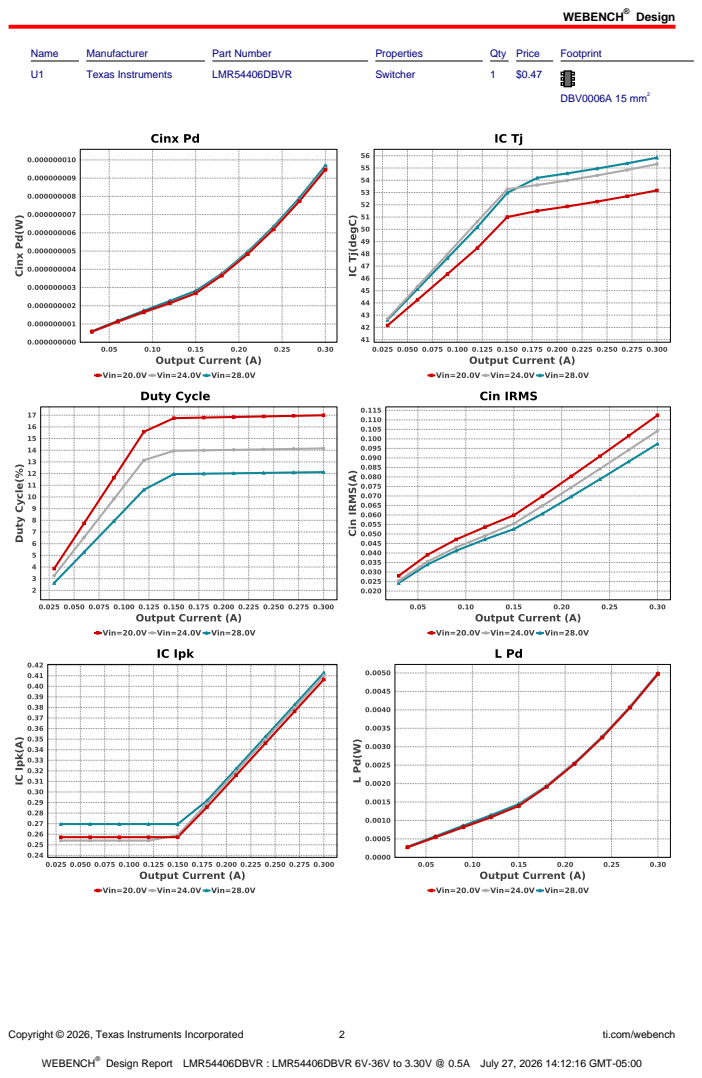
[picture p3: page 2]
Design; Copyright © 2026, Texas Instruments Incorporated; ti.com/webench; Name; Manufacturer; Part Number; Properties; Qty Price; Footprint; Texas Instruments; LMR54406DBVR; Switcher; DBV0006A 15 mm²

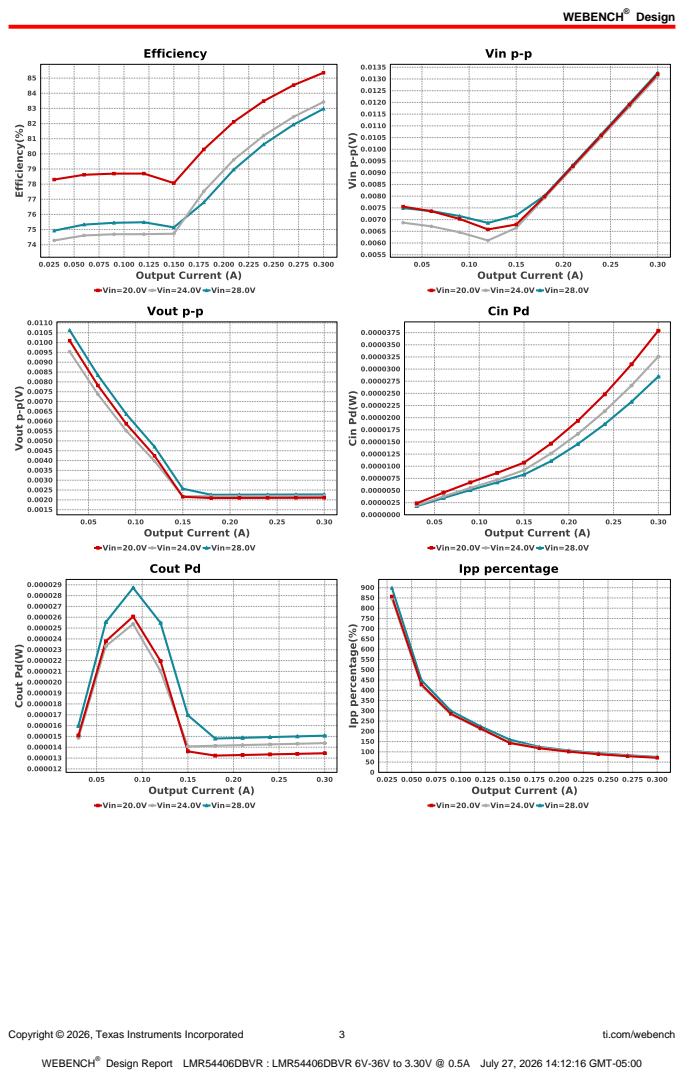
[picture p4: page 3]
Copyright © 2026, Texas Instruments Incorporated; ti.com/webench

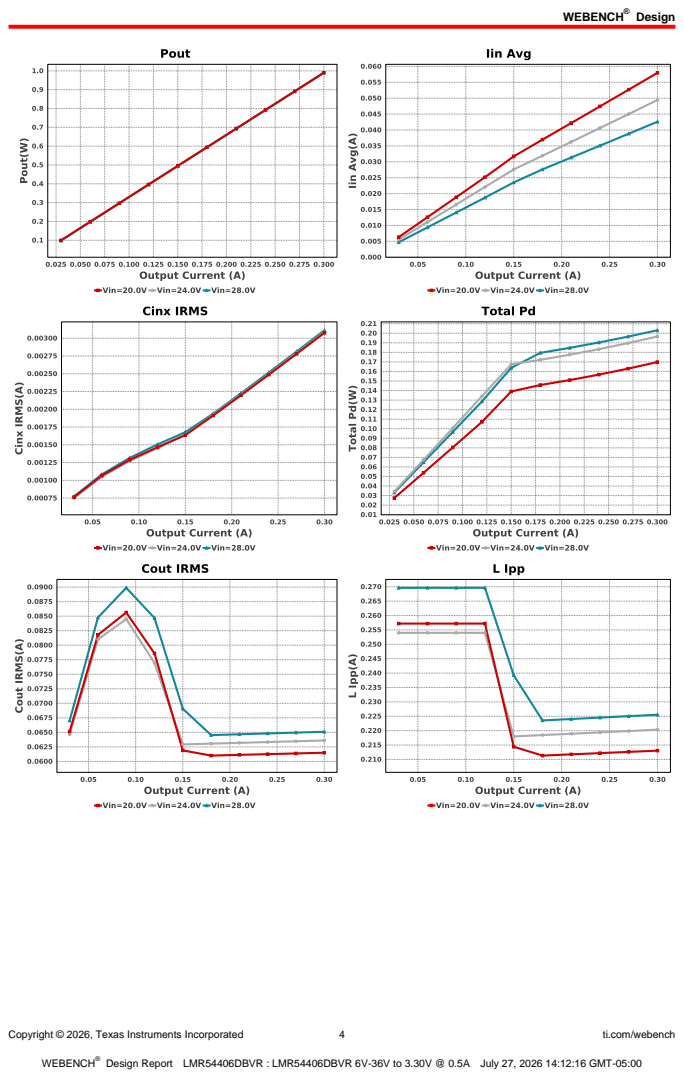
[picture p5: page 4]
Copyright © 2026, Texas Instruments Incorporated; ti.com/webench

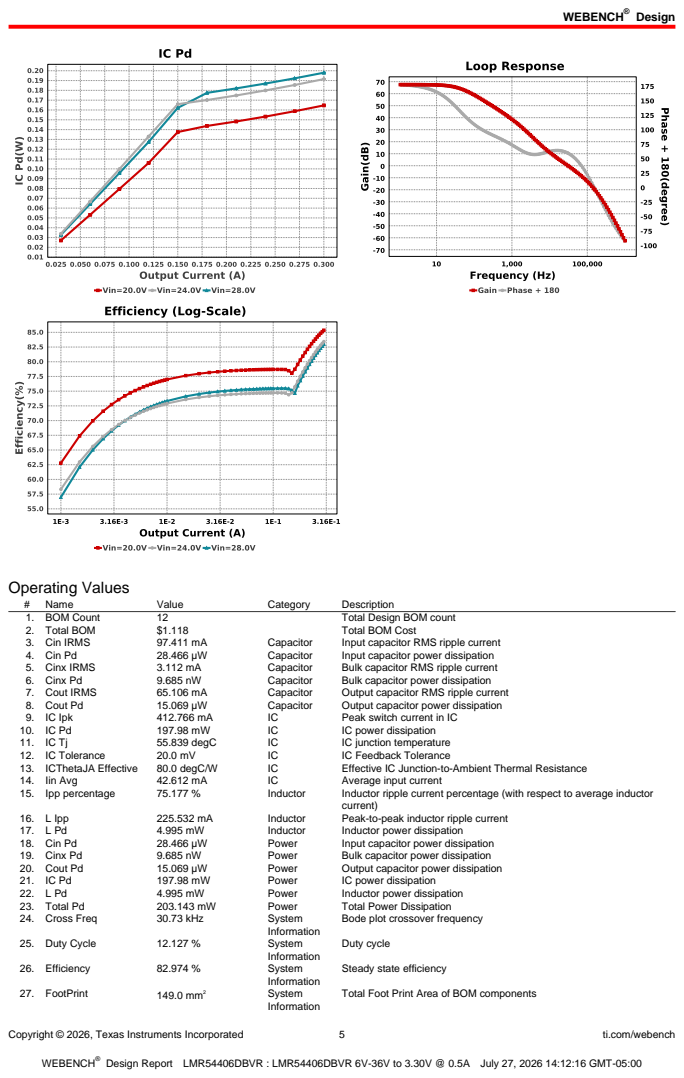
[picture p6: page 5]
Copyright © 2026, Texas Instruments Incorporated; ti.com/webench; Operating Values; Name; Value; Category; Description; 1. BOM Count; Total Design BOM count; 2. Total BOM; Total BOM Cost; 3. Cin IRMS; Capacitor; Input capacitor RMS ripple current; 4. Cin Pd; Input capacitor power dissipation; 5. Cinx IRMS; Bulk capacitor RMS ripple current; 6. Cinx Pd; Bulk capacitor power dissipation; 7. Cout IRMS; Output capacitor RMS ripple current; 8. Cout Pd; Output capacitor power dissipation; 9. IC Ipk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

Bode plot crossover frequency

Steady state efficiency

Total Foot Print Area of BOM components

Copyright © 2026, Texas Instruments Incorporated | 6 | ti.com/webench
# | Name | Value | Category | Description

28. Frequency | 1.1 MHz | System
| | | Information | Switching frequency
29. Gain Marg | -19.694 dB | System
| | | Information | Bode Plot Gain Margin
30. Iout | 300.0 mA | System
| | | Information | Iout operating point
31. Low Freq Gain | 67.505 dB | System
| | | Information | Gain at 1Hz
32. Mode | CCM | System
| | | Information | Conduction Mode
33. Phase Marg | 60.077 deg | System
| | | Information | Bode Plot Phase Margin
34. Pout | 990.0 mW | System
| | | Information | Total output power
35. Vin | 28.0 V | System
| | | Information | Vin operating point
36. Vin p-p | 13.267 mV | System
| | | Information | Peak-to-peak input voltage
37. Vout | 3.3 V | System
| | | Information | Operational Output Voltage
38. Vout Actual | 3.327 V | System
| | | Information | Vout Actual calculated based on selected voltage divider resistors
39. Vout Tolerance | 4.073 % | System
| | | Information | Vout Tolerance based on IC Tolerance (no load) and voltage divider resistors if applicable
40. Vout p-p | 2.278 mV | System
| | | Information | Peak-to-peak output ripple voltage

## Design Inputs

Name | Value | Description
| Iout | | 300.0 m | Maximum Output Current
VinMax | 28.0 | Maximum input voltage
VinMin | 20.0 | Minimum input voltage
Vout | 3.3 | Output Voltage
| base_pn | | LMR54406 | Base Product Number
source | DC | Input Source Type
Ta | 40.0 | Ambient temperature


Copyright © 2026, Texas Instruments Incorporated | 7 | ti.com/webench

## Assembly

## Component Testing

Some published data on components in datasheets such as Capacitor ESR and Inductor DC resistance is based on conservative values that will guarantee that the components always exceed the specification. For design purposes it is usually better to work with typical values. Since this data is not always available it is a good practice to measure the Capacitance and ESR values of Cin and Cout, and the inductance and DC resistance of L1 before assembly of the board. Any large discrepancies in values should be electrically simulated in WEBENCH to check for instabilities and thermally simulated in WebTHERM to make sure critical temperatures are not exceeded.
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

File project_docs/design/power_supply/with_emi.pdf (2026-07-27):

## WEBENCH ® Design Report

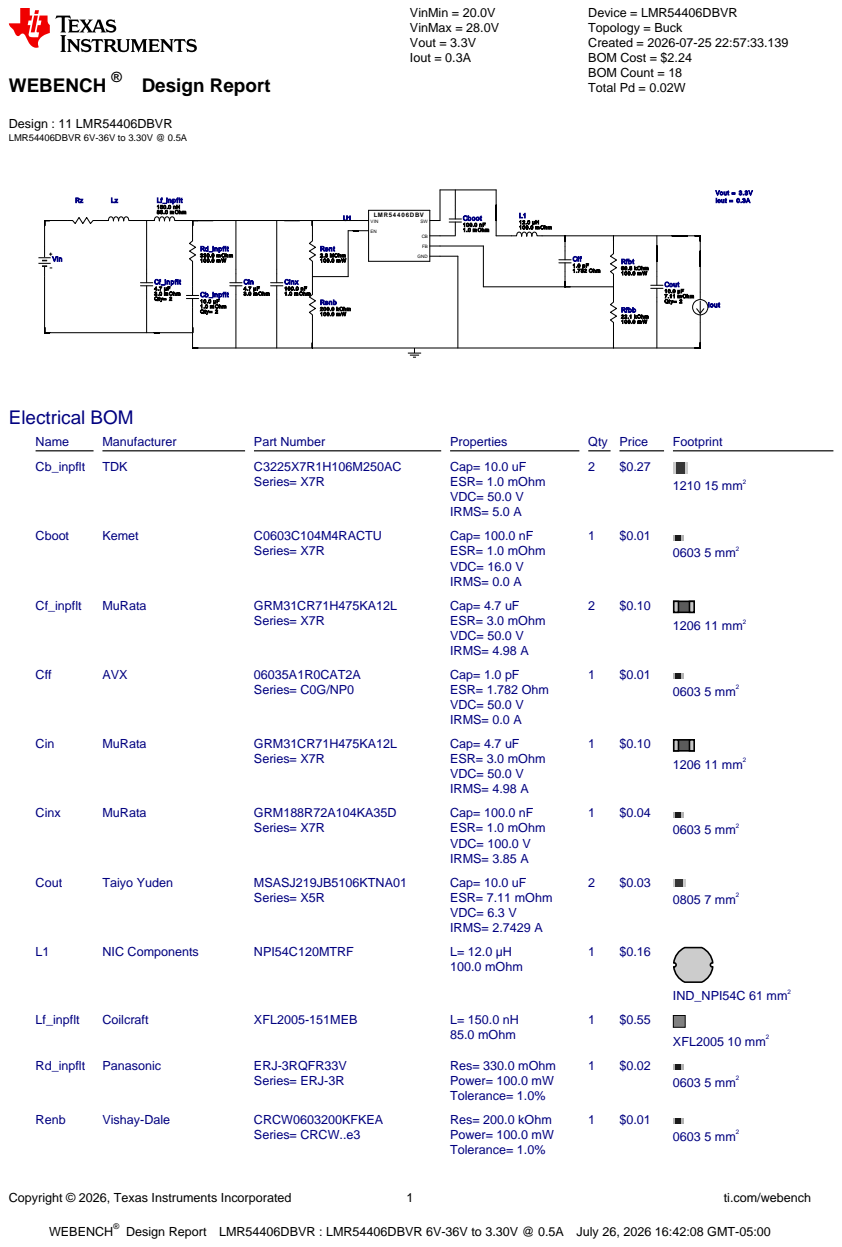
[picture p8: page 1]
Copyright © 2026, Texas Instruments Incorporated; ti.com/webench; WEBENCH®; Design : 11 LMR54406DBVR LMR54406DBVR 6V-36V to 3.30V @ 0.5A; VinMin = 20.0V VinMax = 28.0V Vout = 3.3V Iout = 0.3A; Device = LMR54406DBVR Topology = Buck Created = 2026-07-25 22:57:33.139 BOM Cost = $2.24 BOM Count = 18 Total Pd = 0.02W; Cinx 100.0 nF 1.0 m Ohm; Cff 1.0 pF; 1.782 Ohm; L1 12.0 µH 100.0 m Ohm; LM R5 4 4 0 6 DBV; GND; VIN; Rfbb 22.1 kOhm 100.0 m W; Rfbt 69.8 kOhm; Vout = 3.3V Iout = 0.3A; Cboot 100.0 nF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

Design Report LMR54406DBVR : LMR54406DBVR 6V-36V to 3.30V @ 0.5A July 26, 2026 16:42:08 GMT-05:00

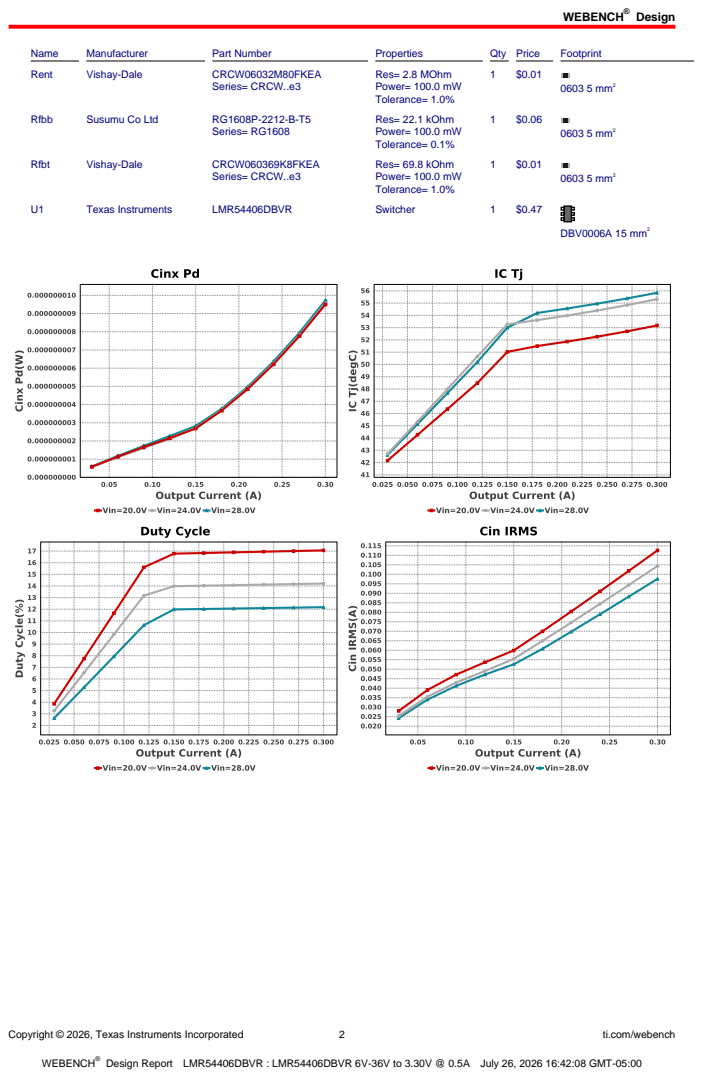
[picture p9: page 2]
Design; Copyright © 2026, Texas Instruments Incorporated; ti.com/webench; Name; Manufacturer; Part Number; Properties; Qty Price; Footprint; Rent; Vishay-Dale; CRCW06032M80FKEA; Series= CRCW..e3; Res= 2.8 MOhm Power= 100.0 mW Tolerance= 1.0%; 0603 5 mm²; Rfbb; Susumu Co Ltd; Series= RG1608; Res= 22.1 kOhm Power= 100.0 mW Tolerance= 0.1%; Rfbt; CRCW060369K8FKEA; Res= 69.8 kOhm Power= 100.0 mW Tolerance= 1.0%; Texas Instruments; LMR54406DBVR; Switcher; DBV0006A 15 mm²

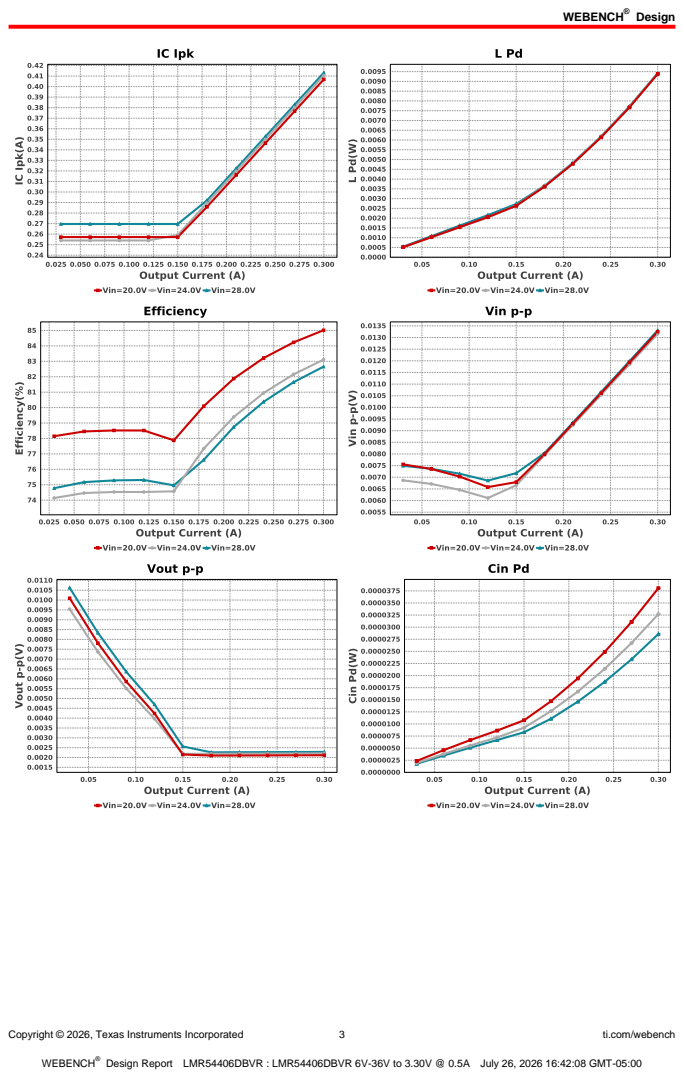
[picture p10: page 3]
Copyright © 2026, Texas Instruments Incorporated; ti.com/webench

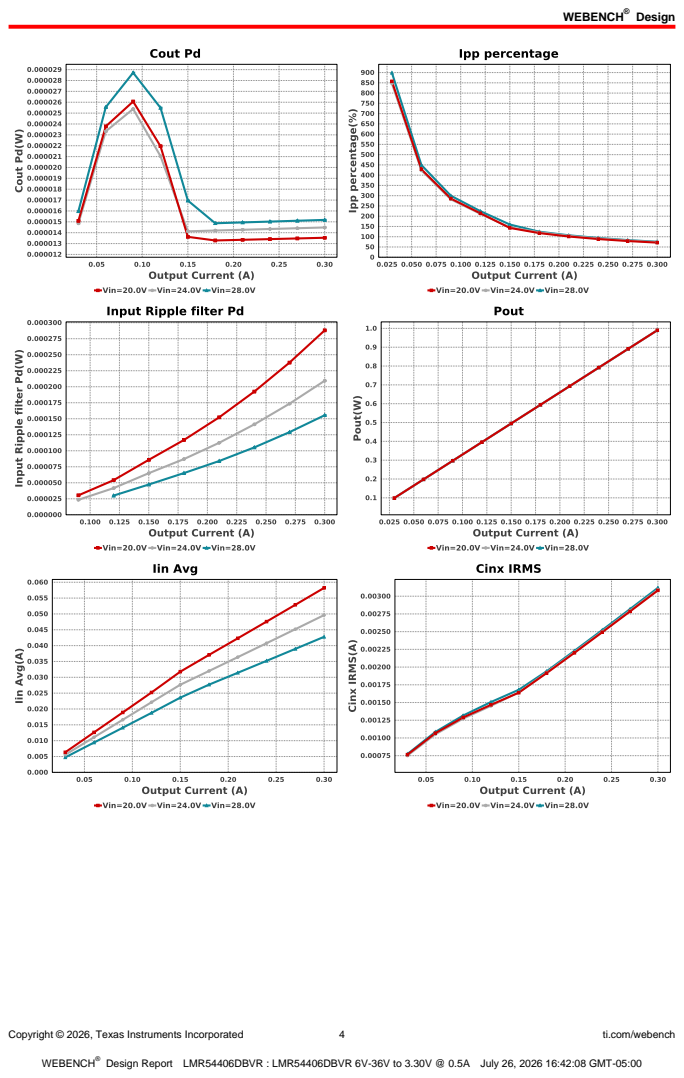
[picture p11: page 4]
Copyright © 2026, Texas Instruments Incorporated; ti.com/webench

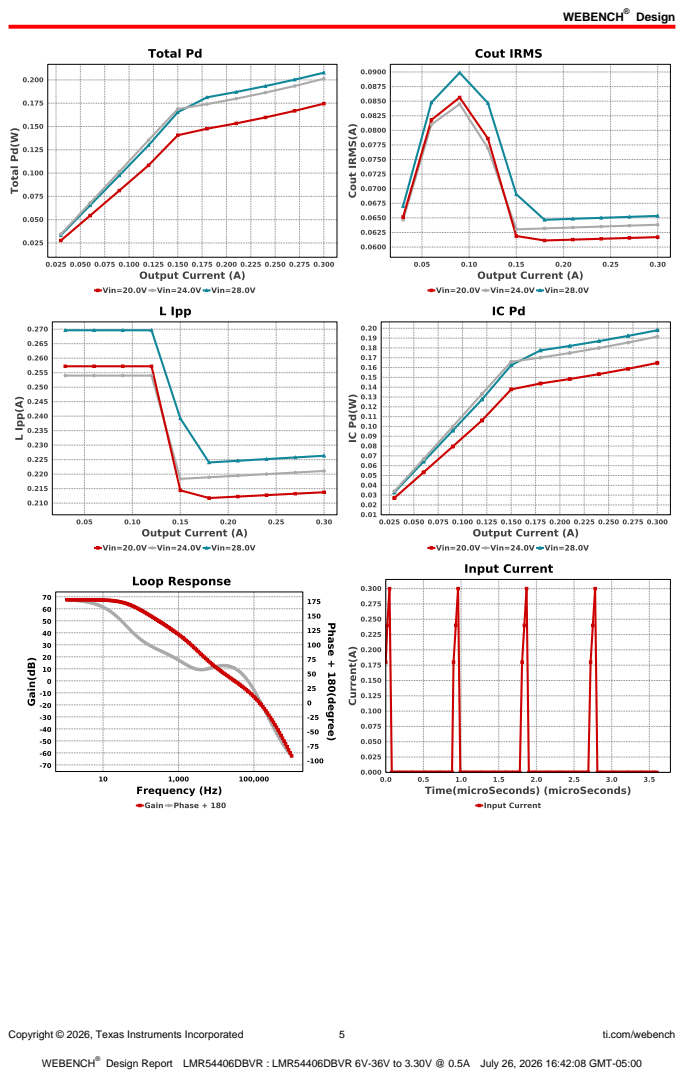
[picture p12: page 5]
Copyright © 2026, Texas Instruments Incorporated; ti.com/webench

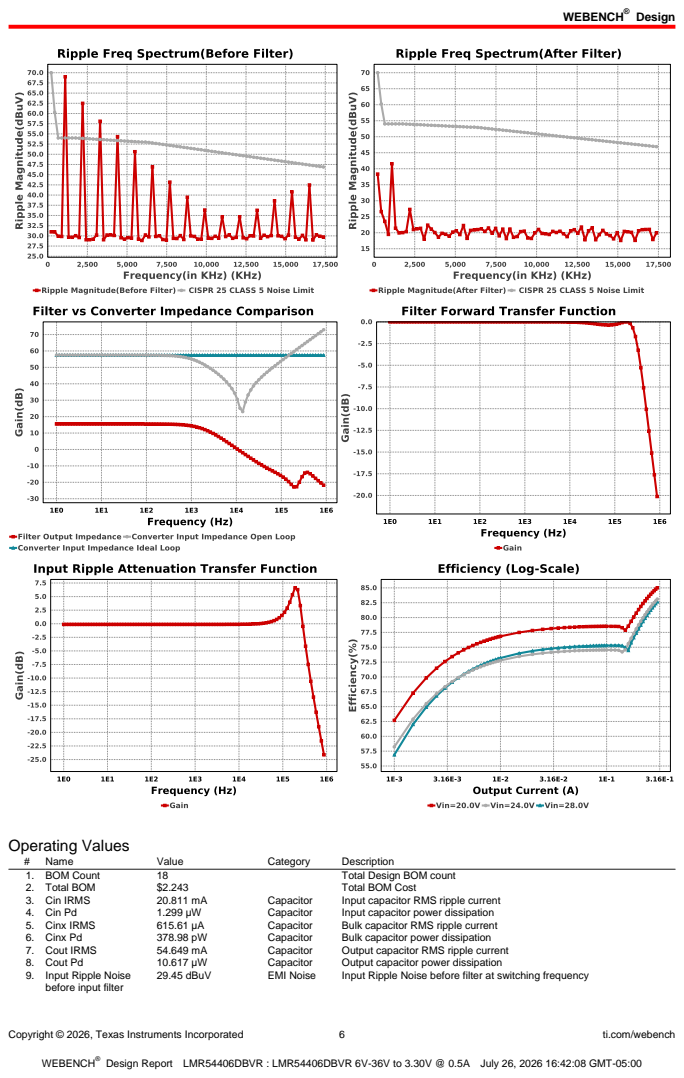
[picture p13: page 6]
Copyright © 2026, Texas Instruments Incorporated; ti.com/webench; Name; Value; Category; Description; 1. BOM Count; Total Design BOM count; 2. Total BOM; Total BOM Cost; 3. Cin IRMS; Capacitor; Input capacitor RMS ripple current; 4. Cin Pd; Input capacitor power dissipation; 5. Cinx IRMS; Bulk capacitor RMS ripple current; 6. Cinx Pd; Bulk capacitor power dissipation; 7. Cout IRMS; Output capacitor RMS ripple current; 8. Cout Pd; Output capacitor power dissipation; 29.45 dBuV; EMI Noise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

Operating Values
9. Input Ripple Noise
before input filter

Copyright © 2026, Texas Instruments Incorporated | 7 | ti.com/webench
# | Name | Value | Category | Description

10. Noise limits defined by
| CISPR Standards | 70.0 dBuV | EMI Noise | Noise limits for CLASS 5 of CISPR 25 standard
11. IC Ipk | 253.992 mA | IC | Peak switch current in IC
12. IC Pd | 22.965 mW | IC | IC power dissipation
13. IC Tj | 41.837 degC | IC | IC junction temperature
14. IC Tolerance | 20.0 mV | IC | IC Feedback Tolerance
15. ICThetaJA Effective | 80.0 degC/W | IC | Effective IC Junction-to-Ambient Thermal Resistance
16. Iin Avg | 3.726 mA | IC | Average input current
17. Ipp percentage | 1.27 k% | Inductor | Inductor ripple current percentage (with respect to average inductor
| | | | current)
18. L Ipp | 253.992 mA | Inductor | Peak-to-peak inductor ripple current
19. L Pd | 338.66 µW | Inductor | Inductor power dissipation
20. Cin Pd | 1.299 µW | Power | Input capacitor power dissipation
21. Cinx Pd | 378.98 pW | Power | Bulk capacitor power dissipation
22. Cout Pd | 10.617 µW | Power | Output capacitor power dissipation
23. IC Pd | 22.965 mW | Power | IC power dissipation
24. L Pd | 338.66 µW | Power | Inductor power dissipation
25. Total Pd | 23.434 mW | Power | Total Power Dissipation
26. Duty Cycle | 2.17 % | System
| | | Information | Duty cycle
27. Efficiency | 73.797 % | System
| | | Information | Steady state efficiency
28. FootPrint | 199.0 mm² | System
| | | Information | Total Foot Print Area of BOM components
29. Frequency | 147.316 kHz | System
| | | Information | Switching frequency
30. Iout | 20.0 mA | System
| | | Information | Iout operating point
31. Mode | PFM | System
| | | Information | Conduction Mode
32. Pout | 66.0 mW | System
| | | Information | Total output power
33. Vin | 24.0 V | System
| | | Information | Vin operating point
34. Vin p-p | 6.896 mV | System
| | | Information | Peak-to-peak input voltage
35. Vout | 3.3 V | System
| | | Information | Operational Output Voltage
36. Vout Actual | 3.327 V | System
| | | Information | Vout Actual calculated based on selected voltage divider resistors
37. Vout Tolerance | 3.357 % | System
| | | Information | Vout Tolerance based on IC Tolerance (no load) and voltage divider resistors if applicable
38. Vout p-p | 10.335 mV | System
| | | Information | Peak-to-peak output ripple voltage
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

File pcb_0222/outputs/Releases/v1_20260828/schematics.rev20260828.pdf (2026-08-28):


0 | 5S
1 | 10S
2 | 20S
3 | 30S
4 | 40S

6 | 60S
7 | 70S
8 | 80S
9 | 90S

4 pairs (Power + GND) to drive 4 LED strips

Designed by Logic Reliance for Satview Broadband Ltd
Sheet: /
File: pcb_0222.kicad_sch
Title: UV Floor Sanitization Unit

Size: A4 | Rev: 20260827
KiCad E.D.A. 10.0.4 | Id: 1/1

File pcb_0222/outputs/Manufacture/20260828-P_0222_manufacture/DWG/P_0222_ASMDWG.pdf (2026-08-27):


Designed by Logic Reliance for Satview Broadband Ltd TVS1

Layer Name | Type | Material | Thickness | Color | Epsilon R | Loss Tangent
F.Silkscreen | Top silk screen | Not specified | Not specified | White | 1 | 0
F.Paste | Top solder paste | | Not specified | | 1 | 0
F.Mask | Top solder mask | Not specified | 0.3937 mils | Green | 3.3 | 0
F.Cu | Copper | | 1.37795 mils | | 1 | 0
Dielectric 1 | Core | FR4 | 59.44882 mils | FR4 natural | 4.5 | 0.02
B.Cu | Copper | | 1.37795 mils | | 1 | 0
B.Mask | Bottom solder mask | Not specified | 0.3937 mils | Green | 3.3 | 0

Sheet:
File: pcb_0222.kicad_pcb
Title: UV Floor Sanitization Unit

Size: A4 | Rev: 20260827
KiCad E.D.A. 10.0.4 | Id: 1/1

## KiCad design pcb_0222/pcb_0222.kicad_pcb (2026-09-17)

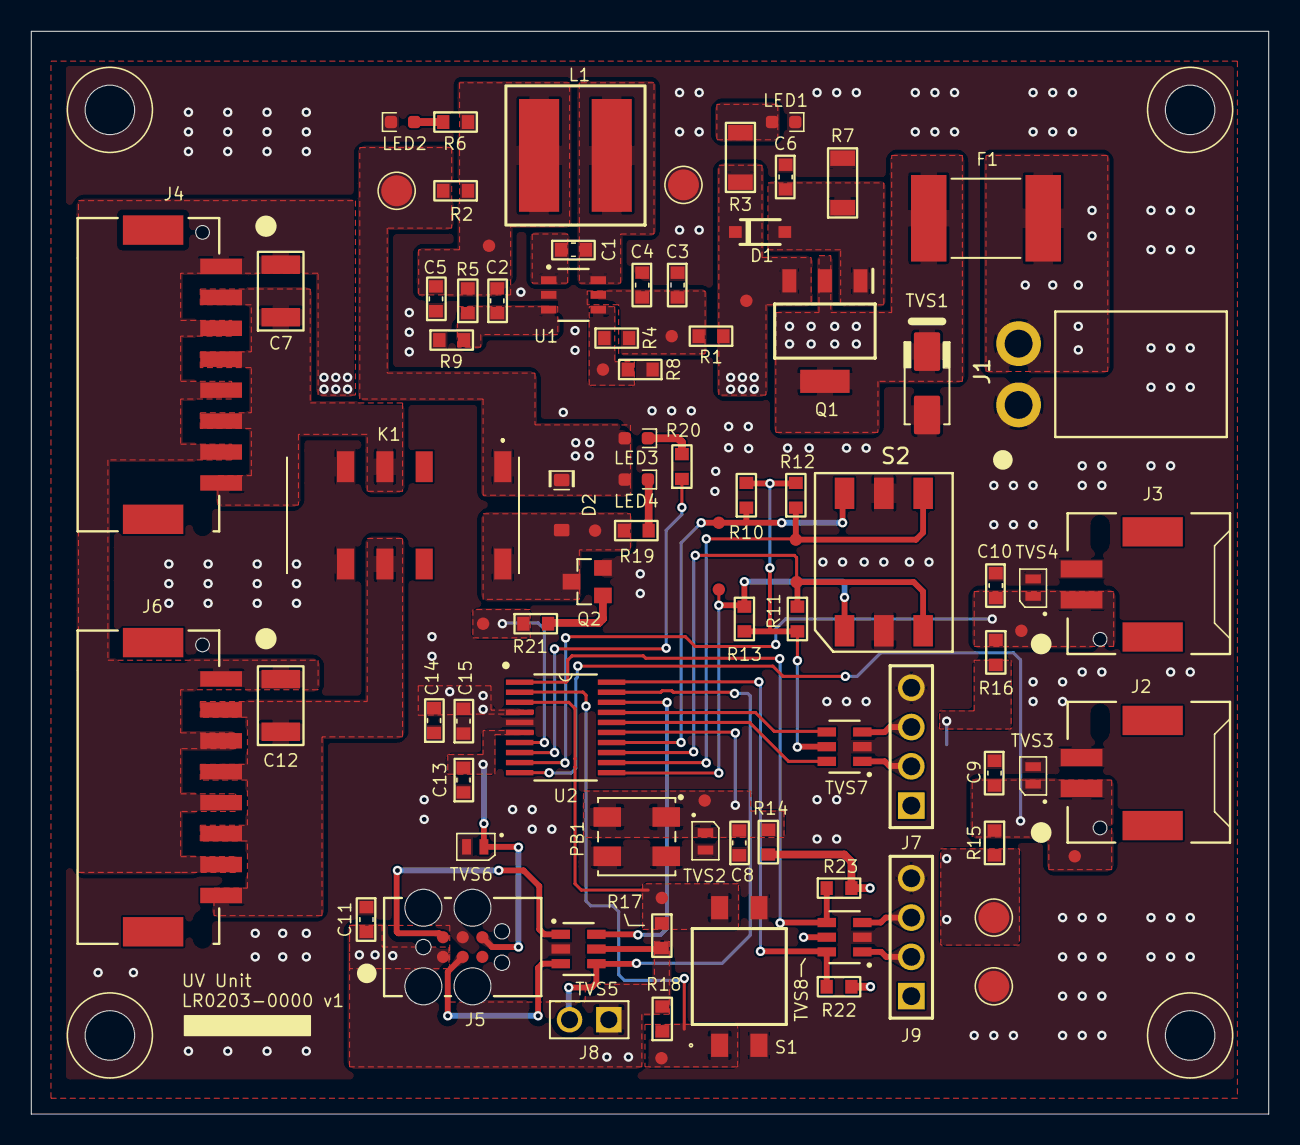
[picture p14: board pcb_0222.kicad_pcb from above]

Board: 2 copper layers, 80.0 x 70.0 mm, 94 parts (0 on the bottom side), 44 nets.

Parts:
C1, C4, C6, C11, C13, C14: 100nF; C_0603
C2: 1pF; C_0603
C3, C15: 4.7uF; C_0603
C5: 10uF; C_0603
C7, C12: 10uF; C_1210_TDK_CGA6_2.8mm_Tall
C8, C9, C10: 10nF; C_0603
D1: BZT52C5V1; SOD-123F
D2: 40V 1A; B5819W
F1: 60V 1A; 0ZCF0100AF2A
J1: S2P-VH
J2, J3: SM02B-PASS-TBT
J4, J6: SM08B-PASS-TBT
J5: TC-2030-IDC; TC2030-IDC
J7, J9: HEADER_MALE_THT_0.1"_4x1; 61300411121
J8: HEADER_MALE_THT_0.1"_2x1; 77311-118-02LF
K1: EE2-3NUH; EE23NUH
L1: 12uH; L_44.88mm3_6.8x6.8mm_Bourns_SRR6038-120Y
LED1, LED2: LTST-C190GKT; LED_0603
LED3: LTST-C190KSKT; LED_0603
LED4: LTST-C190KRKT; LED_0603
M1, M2, M3, M4: mounting_hole_M3_NPTH
PB1: 7914J-1-000
Q1: BSP170PH6327XTSA1; SOT-223-4
Q2: BC817-16; SOT-23-3
R1, R2: 0R; R_0603
R3: 2.2K; R_1206
R4: 2.87M; R_0603
R5: 69.8K; R_0603
R6, R19, R20: 120R; R_0603
R7: 3.6K; R_1206
R8: 200K; R_0603
R9: 22.1K; R_0603
R10, R11, R12, R13, R14, R15, R16, R17, R18: 10K; R_0603
R21: 1K; R_0603
R22, R23: 4K7; R_0603
S1: DS04-254-2-02BK-SMT-TR
S2: CD10RM0SB
TP1, TP2, TP3, TP4: TP_SMD_2mm
TP5, TP6, TP7, TP8, TP9, TP10, TP11, TP12, TP13, TP14, TP15, TP16, TP17, TP18, TP19: TP_SMD_0.8mm
TVS1: 26V; DO-214AC
TVS2, TVS3, TVS4, TVS6: 3V3; 2-DFN_(1.6x1)
TVS5, TVS7, TVS8: USBLC6-2SC6; SOT-23-6 [2.8x2.93x1.1,P=0.95]mm
U1: LMR54406DBVR; SOT-23-6
U2: STM32C011F6P6; TSSOP-20 [6.4x4.4x1.2,P=0.65]mm

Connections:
+3V3: C11.2, C14.2, C15.2, D2.C, J5.1 (VREF), J7.1, J8.1, J9.1, K1.1 (COIL+), LED3.A, LED4.A, R2.2, R10.2, R11.2, R12.2, R13.2, R14.2, R15.2, R16.2, R17.2, R18.2, R22.2, R23.2, TP3.1, TP4.1, TVS5.5 (VBUS), TVS7.5 (VBUS), TVS8.5 (VBUS), U2.4 (VDD/VDDA)
/FB: C2.1, R5.1, R9.2, U1.3 (FB)
/MCU_BCD0: R13.1, S2.1, TP9.1, U2.11 (PA4)
/MCU_BCD1: R12.1, S2.2, TP13.1, U2.12 (PA5)
/MCU_BCD2: R11.1, S2.4, TP15.1, U2.13 (PA6)
/MCU_BCD3: R10.1, S2.8, TP17.1, U2.14 (PA7)
/MCU_DIP1: R18.1, S1.1, TP14.1, U2.2 (PC14-OSCX_IN)
/MCU_DIP2: R17.1, S1.3, TP16.1, U2.3 (PC15-OSCX_OUT)
/MCU_LED: R20.1, U2.8 (PA1)
/MCU_RELAY: R21.1, TP19.1, U2.7 (PA0)
/MCU_SW1: C10.2, J3.1, R16.1, TP12.1, TVS4.C, U2.9 (PA2)
/MCU_SW2: C9.2, J2.1, R15.1, TP11.1, TVS3.C, U2.10 (PA3)
/MCU_TEST: C8.2, PB1.1, PB1.2, R14.1, TP10.1, TVS2.C, U2.15 (PA8)
/NRST: C13.2, J5.6 (NRST), TVS6.C, U2.6 (PF2-NRST)
/RX1: TVS7.4 (I/O2), U2.17 (PA12[PA10])
/SCL1: R23.1, TVS8.4 (I/O2), U2.1 (PB7)
/SDA1: R22.1, TVS8.6 (I/O1), U2.20 (PB6)
/SW: C1.2, L1.1, U1.6 (SW)
/SWCLK: J8.2, TVS5.4 (I/O2), U2.19 (PA14-BOOT0)
/SWDIO: TVS5.6 (I/O1), U2.18 (PA13)
/TX1: TVS7.6 (I/O1), U2.16 (PA11[PA9])
GND: C3.1, C4.1, C5.1, C6.1, C8.1, C9.1, C10.1, C11.1, C13.1, C14.1, C15.1, J1.1, J2.2, J3.2, J5.4 (GND), J7.4, J9.4, K1.5 (NO_1), K1.8 (NO_2), LED1.K, LED2.K, PB1.3, PB1.4, Q2.2 (E), R7.1, R8.1, R9.1, S1.2, S1.4, S2.C1, S2.C2, TP1.1, TP2.1, TVS1.A, TVS2.A, TVS3.A, TVS4.A, TVS5.2 (GND), TVS6.A, TVS7.2 (GND), TVS8.2 (GND), U1.2 (GND), U2.5 (VSS/VSSA)
unnamed: C2.2, C5.2, L1.2, R2.1, R5.2, R6.2, TP7.1
unnamed: C6.2, D1.A, Q1.1, R7.2
unnamed: F1.1, Q1.2 (D), Q1.4 (D), TVS1.C
unnamed: J5.3 (SWCLK), TVS5.3 (I/O2)
unnamed: J5.2 (SWDIO), TVS5.1 (I/O1)
unnamed: J7.2, TVS7.1 (I/O1)
unnamed: J7.3, TVS7.3 (I/O2)
unnamed: J9.2, TVS8.1 (I/O1)
unnamed: J9.3, TVS8.3 (I/O2)
unnamed: D2.A, K1.12 (COIL-), Q2.3 (C), R19.1, TP18.1
unnamed: C7.1, J4.2, J4.4, J4.6, J4.8, K1.4 (COM_1)
unnamed: C12.1, J6.2, J6.4, J6.6, J6.8, K1.9 (COM_2)
unnamed: LED1.A, R3.1
unnamed: LED2.A, R6.1
unnamed: LED3.K, R20.2
unnamed: LED4.K, R19.2
unnamed: Q2.1 (B), R21.2
unnamed: C1.1, U1.1 (CB)
unnamed: R4.1, R8.2, TP8.1, U1.4 (EN)
unnamed: C3.2, C4.2, R1.2, R4.2, TP6.1, U1.5 (VIN)
VB: F1.2, J1.2
VB_IP: C7.2, C12.2, D1.C, J4.1, J4.3, J4.5, J4.7, J6.1, J6.3, J6.5, J6.7, Q1.3 (S), R1.1, R3.2, TP5.1

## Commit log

2026-07-27 On Schematics
    [WBBOMDesign11.csv]
2026-07-28 SCH without MCU
    [DBV0006A.stp, WBBOMDesign11.csv, pcb_0222.kicad_pcb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]
2026-07-28 Remove accidental embedded KiCad history repo
2026-07-28 Schematic On Review
    [TSSOP20_STM.step, UV Floor - Processor Pinout - REV00.xlsx, pcb_0222.kicad_sch]
2026-07-30 Footprints On Review
    [TSSOP20_STM.step, pcb_0222.kicad_sch]
2026-07-30 Placement on Review
    [DBV0006A.stp, pcb_0222.kicad_pcb, pcb_0222.kicad_sch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]
2026-08-02 Working on SCH review
    [UV Floor - Processor Pinout - REV00.xlsx, UV Floor - Processor Pinout - REV01.xlsx, pcb_0222.kicad_sch]
2026-08-02 Ignore KiCad lock files
2026-08-02 SCH review comments fixed
    [pcb_0222.kicad_pcb, pcb_0222.kicad_sch, pcb_0222.step]
2026-08-10 working on Layout
    [pcb_0222.kicad_pcb, pcb_0222.kicad_sch]
2026-08-11 Layout Ready for Review
    [pcb_0222.kicad_pcb, pcb_0222.kicad_sch]
2026-08-16 Layout Review Pending + Preliminary Manufacturer Package Generated
    [pcb_0222.kicad_pcb, pcb_0222.kicad_sch, pcb_0222.step]
2026-08-17 Board characteristics add into F.Fab and ASM DWG + UID add into Silkscreen Layer
    [P_0222_MODEL.step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]
2026-08-18 C7, C12 PARTNO upsated + LED4 VALUE updated + S2 MPN changed to CD10RM0SB
    [T-1Y5W961730A-6units-pcb_0222_EBOM_LogicReliance(2026-08-18).xls, pcb_0222.kicad_pcb, pcb_0222.kicad_sch]
2026-08-27 C5, C7, C12 PARTNO and D1, R7 VALUE and PARTNO changed after preliminary layout review
    [pcb_0222.kicad_pcb, pcb_0222.kicad_sch]
2026-08-27 Layout Review Pass
    [P_0222_MODEL.step, T-1Y5W961730A-6units-pcb_0222_EBOM_LogicReliance(2026-08-18).xls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]
2026-08-28 Ready for First Release - Complete Package
    [P_0222_MODEL.step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]
2026-08-28 First Release
    [EBOM.rev20280828.xlsx]
2026-09-17 SP1103C-01UTG schematic symbol updated
    [pcb_0222.kicad_pcb, pcb_0222.kicad_sch]

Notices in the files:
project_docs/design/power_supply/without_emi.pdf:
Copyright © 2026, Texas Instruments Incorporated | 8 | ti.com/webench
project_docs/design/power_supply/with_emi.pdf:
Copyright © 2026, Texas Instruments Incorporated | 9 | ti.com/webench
